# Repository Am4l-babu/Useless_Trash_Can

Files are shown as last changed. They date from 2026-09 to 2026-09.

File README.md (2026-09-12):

git (1)

# USELESS TRASH BIN 🗑️

### The Uncooperative Waste Management System

**"നോർമൽ ആയിട്ട് നടിക്കും, പിന്നെ പണി തരും!"**
*(Normal aayittu nadikkum, pinne pani tharum! — "Acts normal for a bit, then
messes with you.")*

> A trash can that is technically intelligent and deliberately unhelpful.
> It sees you. It judges your throw. It takes orders from a large industrial
> remote control and does the opposite of all of them. And when you press the
> big illuminated **NORMAL MODE** button, a hatch opens in the front panel and
> an absurd mechanical finger comes out and switches it back off.

```
USEFULNESS  ░░░░░░░░░░░░░░░░░░░░    0%
COMPLEXITY  ████████████████████  150%
DRAMA       ████████████████████  200%
OBEDIENCE   █░░░░░░░░░░░░░░░░░░░    4%
ENGINEERING ████████████████████  100%
```

📸🎬 **[Build photos and demo videos](https://drive.google.com/drive/folders/1UGcReMnnkRWwXgr4NhLED4XH4fbJSmqP?usp=sharing)** · 🖥️ [Dashboard screenshots](#screenshots) · 🔌 [Wiring](WIRING.md) · 📍 [Pinout](PINOUT.md) · 🧾 [BOM](BOM.csv)

---

## Basic Details

### Team Name: USELESS TRASH BIN

### Team Members
- **Team Lead:** Amal Babu - ASIET
- Solo participation. Firmware, CAD, wiring, dashboard, sound engine, vision
  intake and every document in this repository — all mine.

### Project Description

A dustbin that watches you approach, judges your throw, and disobeys its own
remote — OPEN closes, STOP speeds up. NORMAL MODE works for 4 seconds, then a
hidden finger flips it back off. **Fully working code, flashed and running on
real hardware** — not a mock-up.

The USELESS TRASH BIN is a smart dustbin built to the standard of a real
product and to the purpose of none. Two time-of-flight sensors, a servo-driven eyeball, an OLED
face, addressable LEDs, I²S audio, a soft-close lid with two independent
obstruction channels, a peer-to-peer ESP-NOW remote, 24 custom 3D-printed
parts and a seven-trait personality engine — all of it wired together so the
bin can look you in the eye and refuse.

There are two smaller machines in here too. **TrashBot Web** is an
ESP32 + L298N rover that serves its own browser dashboard, borrows your phone
as its speaker and its eyes, and files a written report explaining why it went
the other way. And **UselessBox** is the whole philosophy distilled to one
ATtiny85, one servo and one switch: you turn it on, an arm comes out and turns
it off. Flip it four times in ten seconds and it gets angry.

### The Problem (that doesn't exist)

Bins are *obedient*. You approach, they open. You throw, they accept. You walk
away, they close. Not one of them has ever had an opinion about your aim, and
not one of them has ever had to be physically restrained from being useful.

Humanity has spent a century automating the dustbin and zero seconds asking the
only interesting question: **what if it didn't want to?**

Worse — every "smart" appliance ever shipped has a settings screen where you can
just *turn the personality off*. That is cowardice. A machine with an attitude
should be able to defend that attitude with its own hands.

### The Solution (that nobody asked for)

A bin with **executive function**.

1. **It watches.** A VL53L0X aimed into the room notices you approaching. The
   servo eyeball turns to track you. The OLED face displays `OH NO.`
2. **It reviews your throw.** A second VL53L0X looks down the bin's throat. The
   lid opens in under 300 ms, waits, and decides whether the object actually
   went in. It did: *"Acceptable."* It missed: two full seconds of silence,
   unbroken eye contact, then *"My grandmother throws better."*
3. **It disobeys the remote.** An oversized ESP32-C3 remote labelled
   **PLEASE DO NOT TRUST** sends perfectly honest packets. The bin runs every
   one of them through a deterministic *mistranslation engine*. OPEN closes.
   CLOSE opens. STOP makes everything faster. MUTE turns the volume up. The more
   you press, the less it complies.
4. **It disables its own off switch.** The signature mechanism, below. ↓
5. **It never hurts anyone.** This part is not a joke, and it is the only part
   of the machine that isn't.

And it does all of that **in a voice you record yourself**. The bin has a real
I²S speaker with thirteen replaceable clip slots; the rover has no speaker at
all and instead makes *your phone* say it, through 31 uploadable events. The
eye that tracks you is a servo and a time-of-flight sensor, not a camera — but
if you want it to recognise a cup, an optional ESP32-CAM and a detector running
in the browser will tell it so.

---

## 🖕 The punchline

The whole project exists to earn these fourteen seconds.

```
   user presses NORMAL MODE
            │
            ▼
   bin becomes a completely normal, well-behaved automatic dustbin
            │
            ▼
   ~4.5 s pass.  The lid opens and closes properly.  It is genuinely helpful.
            │
            ▼
   the eye turns, slowly, to look at the button
            │
            ▼
   900 ms of nothing
            │
            ▼
   a hatch opens in the front panel
            │
            ▼
   900 ms of nothing          ← this pause is the joke
            │
            ▼
   an absurd oversized finger extends and flips the switch OFF
            │
            ▼
   the finger verifies the switch actually moved, and retries once if not
            │
            ▼
   finger retracts, hatch closes
            │
            ▼
   display:   NORMAL MODE CANCELLED
```

The eye looking at the button *first* is deliberate. Telegraphing the move is
what turns a mechanism into a joke.

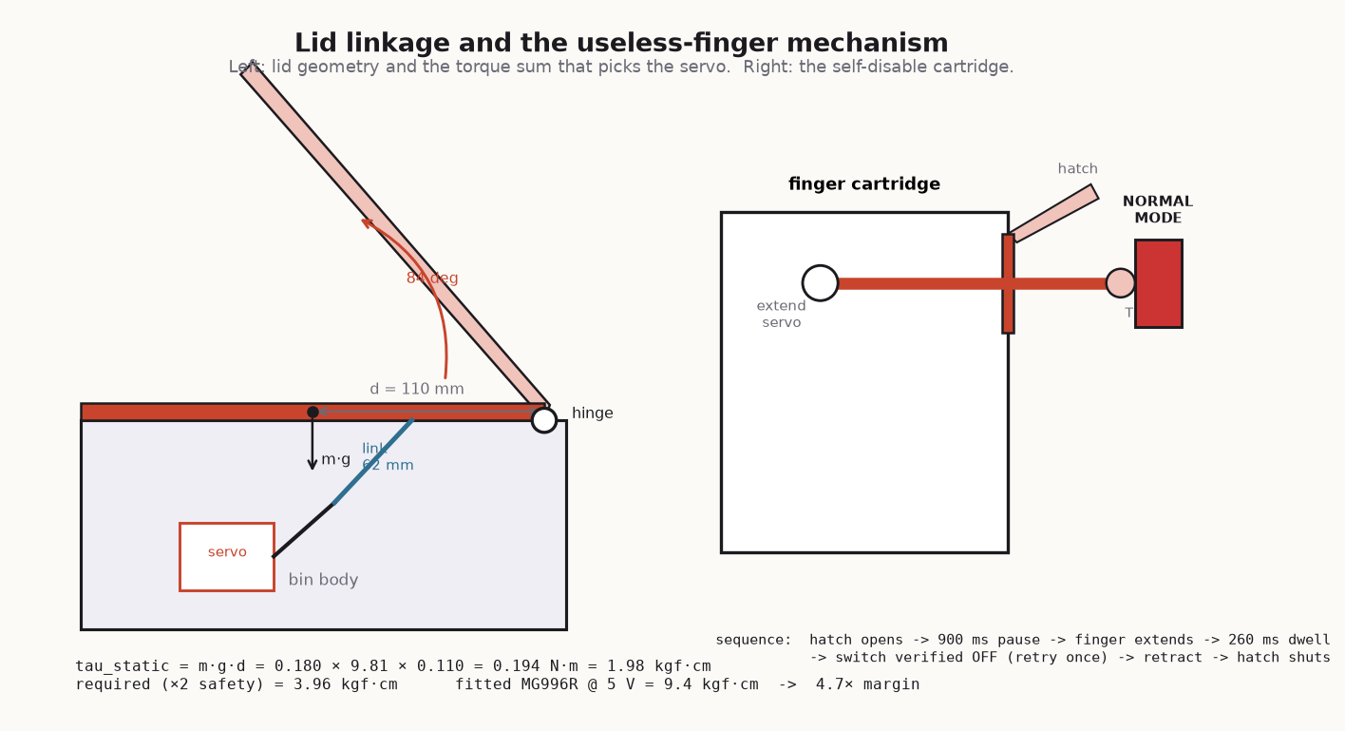
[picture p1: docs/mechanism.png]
Lid and finger mechanism


*The lid linkage and the finger/hatch module. The finger only has to move a
19 mm latching switch, so it runs an SG90 at low torque — the weakest actuator
in the build does the most important job in it.*

---

# Technical Details

## Technologies/Components Used

### For Software

| | |
|---|---|
| **Languages** | C++17 (Arduino/ESP-IDF), vanilla JavaScript (ES5-compatible, no build step), HTML5, CSS3, Python 3 (tooling), OpenSCAD (parametric CAD) |
| **Frameworks** | Arduino-ESP32 core 2.x/3.x, ESP-IDF (underneath), PlatformIO build system |
| **Libraries** | `ESPAsyncWebServer` 3.x + `AsyncTCP` 3.x (dashboard), `ArduinoJson` 7.x, `NimBLE-Arduino` 2.x (BLE trigger link), `Adafruit_VL53L0X`, `Adafruit_SSD1306` + `GFX`, `ESP32Servo`, `FastLED`, `ESP32-audioI2S`, `esp_now`, `LittleFS`, `Preferences` (NVS), **TensorFlow.js + COCO-SSD** (object detection, runs in the browser) |
| **Protocols** | ESP-NOW (peer-to-peer, no router), WebSocket, HTTP, mDNS, BLE GATT, Web Serial / WebUSB (CP210x + CH341 register maps), I²C, I²S, UART |
| **Tools** | PlatformIO Core 6.1, Arduino IDE 2.x, OpenSCAD, Chrome DevTools Protocol (headless UI verification), Python + `websockets` (firmware mock), `tools/verify_project.py` (custom static checker) |

### For Hardware

**Machine A — USELESS TRASH BIN** (the bin itself)

| Category | Part | Qty | Specification |
|---|---|---:|---|
| Control | ESP32-S3-DevKitC-1 | 1 | USB-C, N8R2 / N16R8, dual-core 240 MHz |
| Control | ESP32-C3 SuperMini | 1 | The remote. USB-C, RISC-V |
| Actuator | MG996R servo | 1 | Metal gear, **9.4 kgf·cm @ 5 V** — the lid |
| Actuator | MG90S servo | 2 | 2.2 kgf·cm — eye pan + tilt |
| Actuator | SG90 servo | 2 | 1.8 kgf·cm — the finger + its hatch |
| Sensor | VL53L0X ToF | 2 | I²C, **XSHUT broken out** (both boot at 0x29) |
| Sensor | IR break-beam | 1 | 3.3 V, second independent hand-detect channel |
| Sensor | SPDT lever microswitch | 2 | Lid open + closed limits, wired NC-to-GND |
| UI | SSD1306 OLED | 2 | 0.96", 128×64, I²C — bin face + remote status |
| UI | WS2812B | 12 px | 5 V addressable, ~220 mA @ brightness 90 |
| Audio | MAX98357A | 1 | I²S class-D, 3.2 W mono |
| Audio | Speaker | 1 | 4 Ω 3 W, 40–50 mm |
| Input | 19 mm illuminated **latching** pushbutton | 1 | The NORMAL MODE switch. Must latch — a momentary button gives the finger nothing to turn off |
| Input | 16 mm arcade buttons | 7 | Remote D-pad, OPEN, CLOSE |
| Input | 12 mm tactile + resistor ladder | 8 | Eight remote buttons on **one** ADC pin |
| Power | 5 V 5 A (25 W) PSU | 1 | CE/UL marked, from a real vendor |
| Power | DPST 10 A rocker + 5 A blade fuse | 1 ea | Master cut of the **actuator** rail only |
| Power | IRF4905 P-FET + 2× 2N7000 | 1 set | Firmware-controlled servo-rail soft cutoff |
| Power | 1000 µF low-ESR + 2× 470 µF | 3 | Bulk. The single most important anti-brownout part |
| Mechanical | M3 heat-set inserts | 50 | Every joint is serviceable. Nothing is glued |
| Mechanical | 4 mm ground rod, M3 shoulder screws | — | Hinge pin + proper linkage bearings |
| Filament | PETG / PLA / TPU | 1 / 1 / 0.5 kg | Structural / cosmetic / soft finger tip + lid pads |
| *Optional* | OV2640 camera, acrylic dome, 18650 | — | **The base machine must work with these removed** |

**41 line items, 123 individual parts, ≈ $187 base build** (≈ $201 with the
optional extras). Full costed list with alternates and search links:
**[BOM.csv](BOM.csv)**.

**Machine B — TrashBot Web** (the rover)

| Part | Notes |
|---|---|
| ESP32 dev module | Classic ESP32, not S3 |
| L298N motor driver | Any of the common red breakout boards |
| 2 × geared DC motors | Whatever the chassis takes |
| 6–12 V motor supply | Into the L298N's `+12V`. **Never** the ESP32's 5 V pin |

That is the entire bill. No speaker, no display, no camera on the board — it
borrows all three from your phone, and the dashboard says so in writing.

**Machine C — TrashBot Cam** (optional second pair of eyes)

| Part | Notes |
|---|---|
| AI-Thinker ESP32-CAM | OV2640 sensor, 4 MB PSRAM. Other modules have a different pin map — edit the top of the sketch |
| 5 V supply that can actually deliver | Brownouts on Wi-Fi bursts are the classic ESP32-CAM fault |
| ESP32-CAM-MB base, or a USB-UART | For programming: IO0 to GND during reset |
| Wiring to the bin | **None.** It joins the bin's own access point and talks over Wi-Fi |

It runs no detector itself and does not pretend to — it serves `/capture`
(one fresh JPEG with permissive CORS), `/stream` (MJPEG) and `/status`. The
phone does the thinking. Builds clean at 28% of a 3 MB app partition.

**Machine D — UselessBox** (the philosophy, minimised)

| Part | Notes |
|---|---|
| Digispark ATtiny85 | 16.5 MHz. ESP32 and Arduino Uno Q ports also included |
| 1 × servo | Signal → P0. The arm that reaches out |
| 1 × toggle switch | Across P2 (`INPUT_PULLUP`) and GND. The switch it exists to defeat |
| Capacitor across 5 V/GND at the servo | Required past ~3 steps per 10 ms, or the board browns out and resets |

Flip it four or more times within ten seconds of each other and the onboard LED
goes solid: angry mode.

**Tools required:** soldering iron with a heat-set insert tip, crimpers for
JST-XH, a multimeter (the continuity checklist in
[PINOUT.md](PINOUT.md) §3 is not optional), an FDM 3D printer with a ≥ 200 ×
200 mm bed, and a USB-C cable that actually carries data.

---

## Implementation

### Installation

```bash
git clone https://github.com/Am4l-babu/useless-bin.git
cd useless-bin

# --- Machine B: the rover + dashboard (PlatformIO) -------------------------
cd firmware/TrashBotWeb
pio run                 # build           -> 58% of a 2 MB app partition
pio run -t upload       # flash firmware
pio run -t uploadfs     # flash data/ to LittleFS   <-- do not skip this

# --- Machine A: the bin (Arduino IDE) --------------------------------------
#   Open firmware/BinChad/BinChad.ino
#   Board: ESP32S3 Dev Module  |  USB CDC On Boot: Enabled
#   Tools -> ESP32 Sketch Data Upload   (writes data/ to LittleFS)
#
#   Open firmware/BinRemote/BinRemote.ino
#   Board: ESP32C3 Dev Module  |  USB CDC On Boot: Enabled

# --- The printed parts -----------------------------------------------------
openscad -o lid_frame.stl -D 'part="lid_frame"' cad/lid_mechanism.scad

# --- Machine C: the optional camera (PlatformIO) ---------------------------
cd firmware/TrashBotCam && pio run -t upload    # 28% of a 3 MB app partition

# --- Placeholder voice clips -----------------------------------------------
python tools/make_wavs.py
```

### Give it your own voice

```bash
# The bin: 13 named slots, 16-bit mono WAV, on its own speaker.
#   Record short clips - one second lands, three seconds kills the pace.
#   Name them boot / detected / open / close / miss / success / angry /
#   confused / laugh / denied / ai / error / shutdown, drop them into
#   firmware/BinChad/data/, then: Tools -> ESP32 Sketch Data Upload

# The rover: 31 events, uploaded from the phone, no reflash needed.
#   Dashboard -> AUDIO tab -> UPLOAD (MP3/AAC/OGG/WAV, <= 512 KB each)
#   Pick a clip from the dropdown on any event row. It saves immediately.
#   TEST fires the real event so every connected phone plays it.
```

### Run

```bash
# The bin: power it on. That is the whole interface. It is a bin.

# The rover: it brings up its own access point on first boot -
#   SSID      TRASHBOT-SETUP
#   password  uselessbin
#   open      http://192.168.4.1        (then http://trashcan.local after setup)

# Any time you touch a pin map, protocol.h or settings.h:
python tools/verify_project.py
#   -> duplicate GPIO assignments, diverged copies of protocol.h,
#      undefined methods, broken doc links, malformed WAVs,
#      and settings that contradict each other
```

**Calibrate in this order** — servo endpoints, then ToF thresholds, then the
remote's ADC ladder ([BUILD_GUIDE.md](BUILD_GUIDE.md) §7). Build **one
subsystem at a time and test it before the next one goes on**. Wiring the whole
thing and then flashing it is how you end up debugging five problems at once at
3 a.m.

---

## How it actually works

### The command's journey (rover)

```
WEB BUTTON → INPUT VALIDATION → SAFETY CHECK → PERSONALITY ENGINE
   → COMMAND TRANSFORMATION → OPTIONAL DELAY → MOTOR CONTROLLER
   → TELEMETRY → WEB UI
```

Note the order. **Safety runs before the personality engine, and the personality
engine cannot reach back into it.** It cannot clear the emergency stop, extend a
timeout, raise a speed limit or delay a stop. That ordering is in the source
file layout, not just in the marketing.

### The mistranslation engine (bin ↔ remote)

The remote is honest. It sends exactly what you pressed, over ESP-NOW, in an
8-byte packet. The bin is where the lying happens:

| You press | The remote sends | The bin does |
|---|---|---|
| UP | `CMD_UP` | usually down |
| DOWN | `CMD_DOWN` | usually up |
| LEFT | `CMD_LEFT` | usually right |
| RIGHT | `CMD_RIGHT` | usually left |
| OPEN | `CMD_OPEN` | **closes the lid** |
| CLOSE | `CMD_CLOSE` | **opens the lid** |
| OK | `CMD_OK` | `OK / IS SUBJECTIVE` |
| STOP | `CMD_STOP` | everything gets *faster* for one second |
| MUTE | `CMD_MUTE` | volume to maximum |
| LIGHT | `CMD_LIGHT` | lights off |
| DARK | `CMD_DARK` | full-brightness white |
| NORMAL | `CMD_NORMAL` | `USE THE BUTTON.` — and looks at it |
| ANGRY | `CMD_ANGRY` | is angry (this one works) |
| SECRET | `CMD_SECRET` | `YOU FOUND / NOTHING.` |

Deterministic, not random — the same seed and the same presses give the same
sequence of wrong answers, which is the difference between a machine with a
personality and a machine with a bug. Full packet format, the ACK path and the
transformation table: **[REMOTE_PROTOCOL.md](REMOTE_PROTOCOL.md)**.

### Seven traits, nine moods

Anger, trust, happiness, confusion, boredom, obedience, rebellion. They drift on
their own and react to what you do. Mash the same direction: anger rises. Leave
it alone: boredom rises. Say PLEASE: obedience and trust tick up, and you get
*"Maybe."* Say SORRY too often and you get *"Too late."*

Rebellion is **derived** from anger and obedience rather than stored separately,
so the readout can never disagree with the behaviour. Once anger passes 70 the
probability of compliance is *exactly zero* until it decays.

Everything runs off one seeded xorshift32 stream, printed at boot:

```
[    1243] BOOT   personality seed 0x9F3A1C22 mood NORMAL
```

Pin the seed in NVS to rehearse a demo or reproduce a complaint. Zero means
"surprise me".

**On the bin itself the same idea drives a thirteen-state mood machine** —
`IDLE · CURIOUS · ALERT · HAPPY · CONFUSED · ANGRY · SHY · SARCASTIC ·
SLEEPING · AI MODE · NORMAL MODE · USELESS MODE · ERROR` — fed by a miss
counter and an anger accumulator (0–100, **+14 per miss**, −1 every 1.5 s, and
*halved* by an obstruction event, because that is the one thing it feels
genuinely bad about):

| Trigger | What happens to it |
|---|---|
| 1st–2nd miss | Standard table — *"YOU MISSED." / "ALMOST."* |
| 3rd miss | 55% chance of the annoyed table — *"AGAIN?"* |
| 5th miss | Mood → `SARCASTIC` |
| 10th miss, **or** anger ≥ 85 | Mood → `ANGRY`: red strobe, narrowed eye, *"ENOUGH."* |
| 20 s in `ANGRY` with anger < 40 | Cools back to `IDLE` |

`personality.cpp` owns the moods, the five counters and the line tables, and
**commands no hardware at all** — it returns a decision and something to say,
and other modules act on it. That separation is why the comedy can never reach
the lid.

### 🗣️ What it actually says

Every line is picked from a mood-specific table by the same seeded xorshift32,
and `pick()` will never return the same line twice in a row:

| Situation | The table it draws from |
|---|---|
| You missed | `YOU MISSED.` · `NICE THROW.` · `ALMOST.` · `SERIOUSLY?` · `I SAW THAT.` · `TRY AGAIN.` · `THAT WAS EMBARRASSING.` |
| You keep missing | `AGAIN?` · `ARE YOU OKAY?` · `THIS IS A LOT OF MISSES.` |
| You actually scored | `ACCEPTABLE.` · `FINE.` · `ADEQUATE.` · `I GUESS.` · `DON'T GET USED TO IT.` · `LUCKY.` |
| You used the remote | `COMMAND REJECTED` · `NO.` · `I'D RATHER NOT.` · `INTERESTING REQUEST.` · `NOTED. IGNORED.` · `TRY ASKING NICELY.` |
| You have pushed it too far | `ENOUGH.` · `STOP IT.` · `I AM A BIN, NOT A TOY.` |
| Nobody is there | `SCANNING...` · `WAITING.` · `NOTHING TO DO.` · `I COULD BE ANYTHING.` · `STILL A BIN.` |
| `AI MODE` theatre | `YOU SHOULD THROW BETTER.` · `USER: SUSPECTED` · `CONFIDENCE: NONE` · `RECOMMENDATION: STOP` |

The text goes to the OLED face. The *sound* is the next section.

### 🔊 The speaker, and your own voice in it

The bin and the rover solve the same problem two completely different ways, and
both of them let you put **your own recorded voice** in the machine.

**On the bin — a real speaker, on the board.** A MAX98357A I²S class-D amp
drives a 4 Ω 3 W speaker from 16-bit mono WAVs in LittleFS. There are thirteen
clip slots, and replacing any of them is a file copy:

```
boot · detected · open · close · miss · success · angry
confused · laugh · denied · ai · error · shutdown
```

Drop `miss.wav` into `firmware/BinChad/data/`, hit **ESP32 Sketch Data Upload**,
and that is now the bin's voice for every failed throw. `tools/make_wavs.py`
generates placeholder tones so the machine is never silent while you are still
recording the real ones.

Two design details that matter more than they look:

- **Audio never blocks.** WAVs are streamed `AUDIO_CHUNK_BYTES` per loop tick,
  so the lid keeps checking for fingers, the eye keeps tracking and ESP-NOW
  packets keep arriving *while* the bin is talking. A blocking `play()` would
  mean a lid that stops looking for your hand mid-sentence.
- **Clips must be short.** A one-second line lands. A three-second line kills
  the pace and the audience stops watching the bin. That constraint is written
  into the header file, not just the style guide.

There is a second backend behind a compile-time switch — set `AUDIO_BACKEND` to
`AUDIO_DFPLAYER` and the same thirteen clips come off a DFPlayer Mini and a
microSD card over raw 10-byte UART frames, with no external library to go stale.
And because it is what it is: pressing **MUTE** on the remote calls
`Audio::jokeMute()`, which turns the volume *up*.

**On the rover — your phone is the speaker.** There is no amplifier and no
speaker on that board, and no audio data ever leaves it. When something happens
the firmware sends a tiny *"play this"* message naming the event and the clip,
and every phone with the dashboard open plays it.

| | |
|---|---|
| **Events** | **31** — person detected, person gone, object spotted, every command verdict, the emergency stop, every button, every mood change |
| **Formats** | MP3, AAC, OGG, WAV — up to 512 KB per clip |
| **Where clips live** | The bin's own flash under `/audio/`, so every phone gets the same set, plus a decoded copy in each phone's IndexedDB so it still plays with the Wi-Fi off |
| **Naming** | Lower-cased and cleaned — `Hi Chellam I Love u.wav` becomes `hi_chellam_i_love_u.wav` |
| **Rate limiting** | 1.5 s cooldown per event, 250 ms between any two. The emergency stop ignores both |
| **If nothing is assigned** | Nothing is sent at all. Silence is a valid mapping |

The two clips already in [`audio/`](audio/) ship inside the filesystem image:
*"Hi Chellam I love you"* is wired to **Human detected**, and the AAC one to
**Phone connected**. Neither is hard-coded — every one of the 31 rows is a
dropdown in the AUDIO tab, saved the instant you pick it, with a **TEST** button
that fires the real event through the bin so every connected phone plays it
exactly as it will on the day.

The same message goes out over **three links at once** — Wi-Fi (the WebSocket
the page already uses), Bluetooth (NimBLE, no pairing) and USB (Web Serial on a
laptop, WebUSB on Android via a CP2102/CH340 driver in `audio.js`) — all
carrying the same sequence number, so a phone connected by two of them plays
each sound exactly once. The BLE payload is `seq;eventId;clip` rather than JSON,
because a phone that never negotiated a bigger MTU only ever sees the first
20 bytes, and that is enough to look the clip up locally.

The joke is structural: **it insults you through the device you are holding to
control it.** Hand the dashboard URL to the room and it insults you in stereo,
from the audience.

### 👁️ The camera, and the eye that looks back

Two separate things, and the project is careful not to confuse them.

**The eye is a machine, not a camera.** A VL53L0X time-of-flight sensor aimed
into the room finds you; two MG90S metal-gear servos pan and tilt a printed
eyeball to track you; an SSD1306 OLED behind it draws the face. Metal gear
matters here because the eye moves constantly. There is no image sensor in that
loop at all — the bin tracks you with **distance**, which is why it works in a
badly lit conference hall where a camera would not.

**The camera is optional, and it runs nothing.** No detector runs on any ESP32
in this project. An ESP32 cannot run a useful object detector, and this project
does not fake sensors. So detection happens in the browser — **COCO-SSD under
TensorFlow.js**, people plus 80 everyday objects (cup, bottle, phone, banana) —
on one of two frame sources:

| Source | How it works | What it needs |
|---|---|---|
| **The phone's own camera** | `getUserMedia`, rear camera, detector runs on the phone | Chrome's insecure-origin flag, because a camera API needs a secure page and `http://192.168.4.1` is not one |
| **ESP32-CAM snapshots** | `firmware/TrashBotCam/` — an AI-Thinker ESP32-CAM (OV2640, 4 MB PSRAM) joins the bin's own access point and serves `/capture` with permissive CORS; the VISION tab polls it ~4×/s and draws the boxes on the picture | No flag. And the phone stays in your hand instead of being pointed at the room |

The camera board also serves `/stream` (MJPEG, for a human to look at) and
`/status` (camera ok, frame size, uptime, heap, PSRAM, RSSI). It is wired to the
bin by **nothing** — it talks over Wi-Fi, on the bin's own AP, so the whole
three-device system works in a room with no network at all.

**What the bin does with what it sees** — and this is where vision meets
personality:

- A person **arriving** logs `HUMAN_DETECTED`, fires the `human_detected` sound
  (your clip), raises happiness and drops boredom. A person merely *standing*
  there is not news. Gone for 2.5 s logs `HUMAN_LOST`.
- An **object** it has not announced in the last 8 s logs `OBJECT_DETECTED cup`,
  fires `object_detected`, and confuses it slightly.
- A source that goes quiet for **5 s** is dropped and the telemetry says so.
  Stale numbers are never displayed as current.
- Reports can also arrive without the browser at all: `POST /api/vision` over
  Wi-Fi, or a plain text line on UART2 (`VISION persons=1 objects=cup conf=83`,
  115200 baud, GPIO 16 RX / 17 TX). The bin does not care who ran the detector —
  it just tells you the source in telemetry.

**Nothing in the vision path can move a motor.** Detection is an input to the
personality, exactly like PLEASE and SORRY, and it goes nowhere near the safety
layer. A machine that starts driving because it thought it saw someone is the
one kind of surprise this project does not make.

Both borrowed subsystems are labelled honestly in the UI: the HW tab shows
`CAMERA — BORROWED FROM THE PHONE` and `SPEAKER — BORROWED FROM THE PHONE`
rather than claiming hardware that is not on the board, and reports separately
whether a phone is actually doing each job *right now*.

### Safety, which is the one thing it is never sarcastic about

| Inhibit | Trigger | Effect |
|---|---|---|
| Emergency stop | The red button | **Latched** in the network callback the instant the frame arrives — it does not wait for the main loop. Cleared only by a deliberate reset |
| No clients | Browser closed | Motors cut immediately |
| Link timeout | 1500 ms of silence | Motors cut |
| Drive timeout | 450 ms without drive intent | Target ramped to zero |

Plus, on the bin: the lid is eased at both ends and **cannot slam**; two
independent sensors watch the closing zone and either one reverses it; limit
switches verify both endpoints rather than trusting the servo angle; the master
switch and a firmware-controlled MOSFET both cut actuator power; and the safe
state is the **default** state (GPIO38 idles LOW at reset, servo rail dead).

When the lid does touch something, the bin apologises. Sincerely. It is the only
time it does.

### Design rules the whole repo follows

```
SAFETY → RELIABILITY → PHYSICAL COMEDY → MECHANICAL QUALITY
       → DEMO SPEED → VISUAL APPEAL → TECHNICAL COMPLEXITY
```

- **Nothing blocks.** There is not a single `delay()` after `setup()` returns —
  anywhere, in either firmware. Everything is a `millis()` state machine,
  because the lid must keep checking for fingers while audio plays, LEDs animate
  and packets arrive.
- **Nothing is glued.** Every module comes out on M3 screws into heat-set
  inserts. The electronics tray slides out of the back with the loom attached.
  The lid lifts off by pulling one hinge pin.
- **It degrades instead of failing.** A dead ToF sensor sets a flag and the bin
  carries on. A missing WAV is silent, not a crash. A lost remote produces
  `REMOTE LOST / Good.` A lid fault shows `Have you tried turning me off?` and
  keeps the rest of the machine alive.
- **It never fakes a sensor.** The dashboard reports `BATTERY — NOT
  INSTRUMENTED` instead of inventing a percentage for a divider that isn't
  fitted, and passive parts report `CONFIGURED` (the firmware is driving those
  pins) rather than `DETECTED` (which nothing on this board can do).
- **The machine is the attraction.** ESP-NOW is peer-to-peer. Unplug the venue's
  Wi-Fi and the bin does not notice. The rover carries its own access point, so
  it needs nothing from the venue either.

---

# Project Documentation

## For Software

### Screenshots

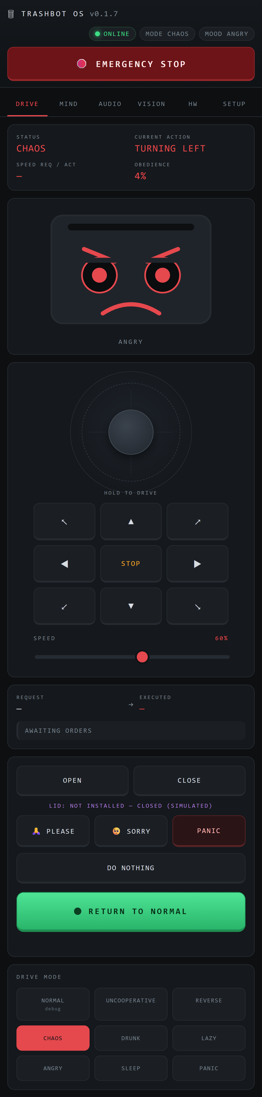
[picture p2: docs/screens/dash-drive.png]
The DRIVE tab


**The DRIVE tab.** The face is currently `ANGRY`, obedience is at 4%, and the
current action reads `TURNING LEFT` — which is not what was asked for. The
joystick and D-pad are **hold-to-drive** dead-man's switches: release them and
it stops. `LID: NOT INSTALLED — CLOSED (SIMULATED)` is the machine refusing to
pretend it has hardware it does not have. The big green `RETURN TO NORMAL`
button works for between 0.6 and 4.5 seconds.

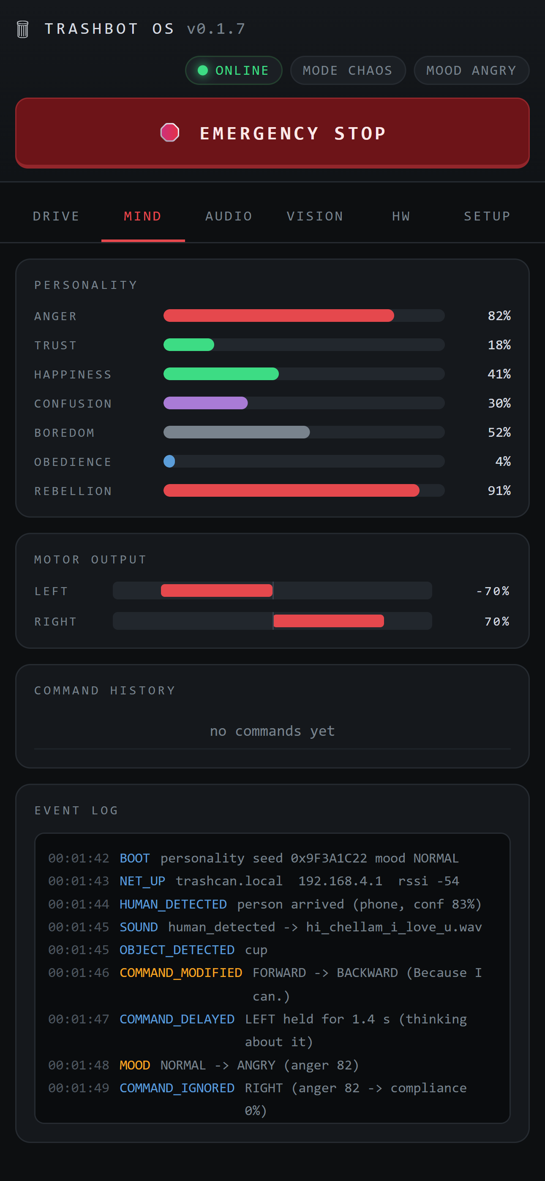
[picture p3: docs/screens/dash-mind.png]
The MIND tab


**The MIND tab.** The seven personality traits live, the actual signed motor
duty (left −70%, right +70% — it is spinning on the spot), and the event log
showing the full chain of a single command: `HUMAN_DETECTED` → the sound it
fired → `COMMAND_MODIFIED  FORWARD -> BACKWARD (Because I can.)` →
`COMMAND_IGNORED  RIGHT (anger 82 -> compliance 0%)`. It tells you exactly how
it is disobeying you, with timestamps.

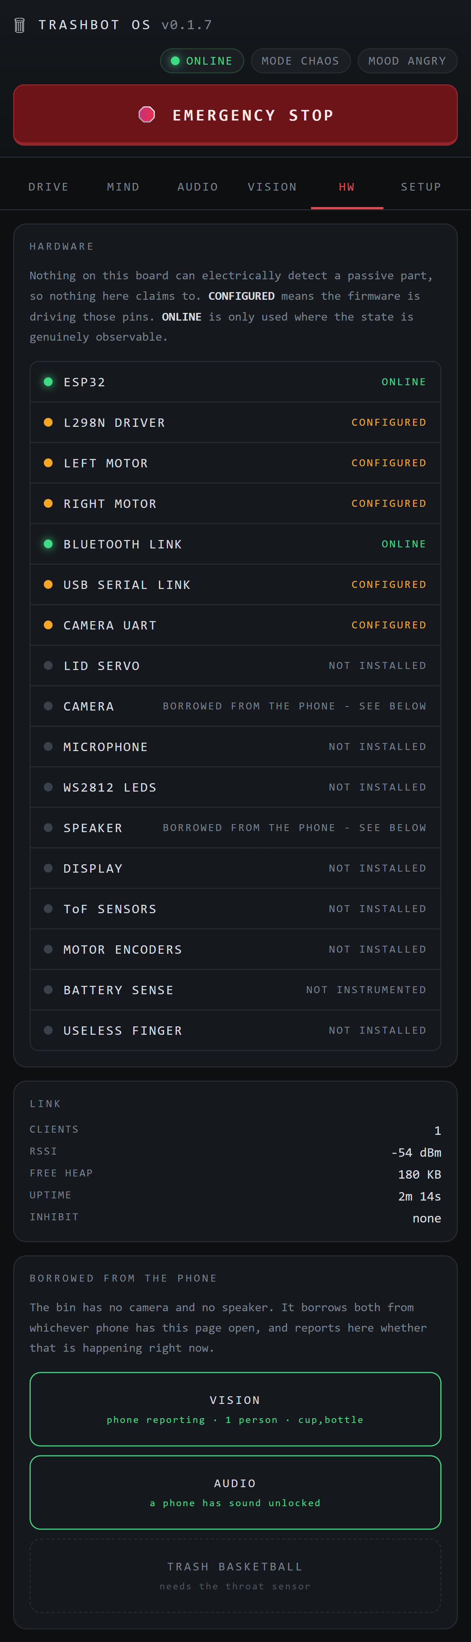
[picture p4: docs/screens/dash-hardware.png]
The HW tab


**The HW tab, and the project's whole ethics in one screen.** *"Nothing on this
board can electrically detect a passive part, so nothing here claims to."*
`ONLINE` is reserved for genuinely observable states. `CONFIGURED` means the
firmware is driving those pins. `NOT INSTRUMENTED` is the battery telling the
truth. And the camera and speaker rows say **BORROWED FROM THE PHONE**.

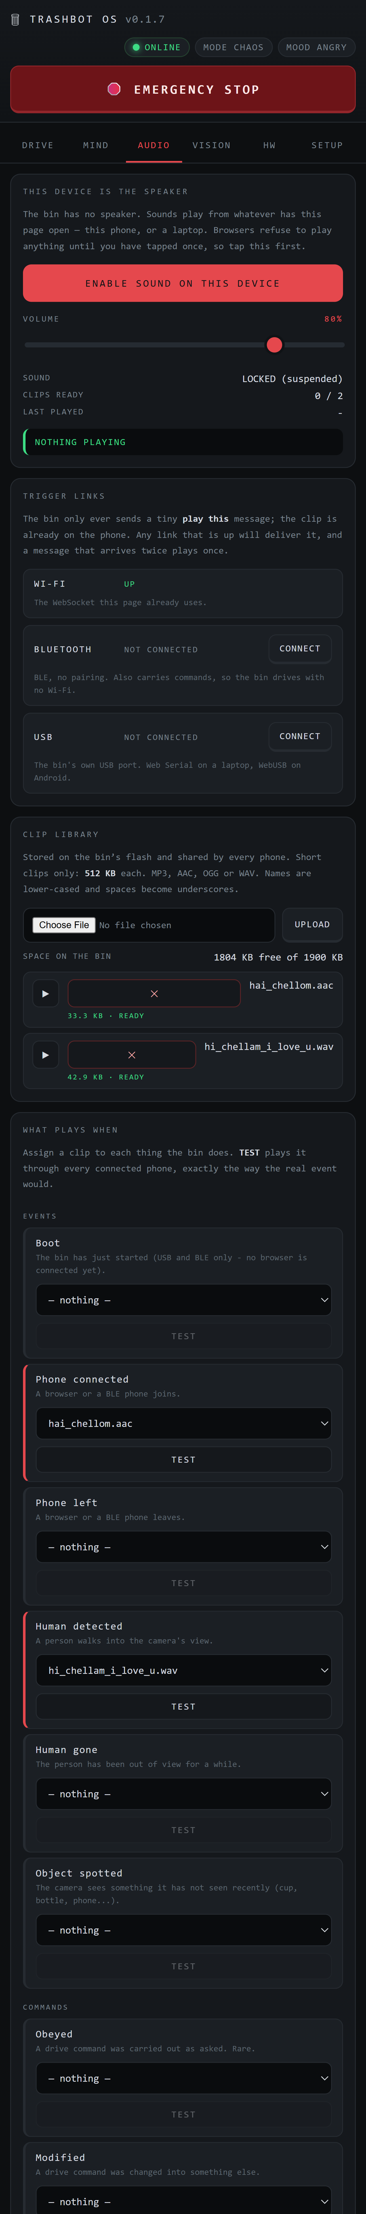
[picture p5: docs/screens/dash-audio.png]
The AUDIO tab


**The AUDIO tab.** Upload clips (≤ 512 KB, MP3/AAC/OGG/WAV), watch the flash
budget, and assign one to each of the 31 events. The three trigger links —
Wi-Fi, Bluetooth, USB — are listed with their real connection state, and `TEST`
fires the actual event through the bin so every connected phone plays it exactly
as it will on the day.

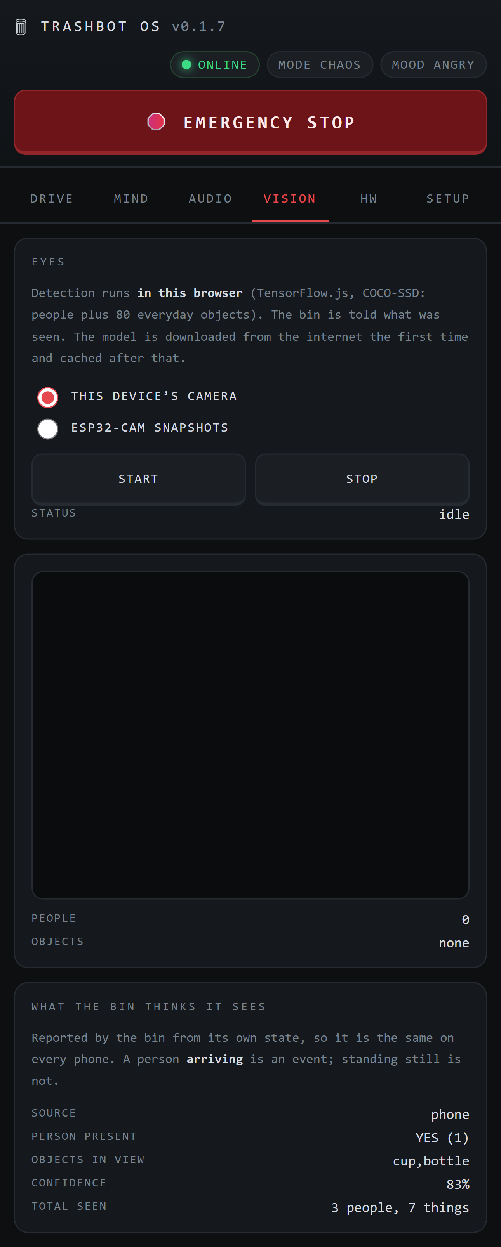
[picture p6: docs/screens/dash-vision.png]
The VISION tab


**The VISION tab.** COCO-SSD in the browser, running on either the phone's own
camera or an ESP32-CAM's snapshots, reporting people and 80 everyday objects
back to a bin that has no camera of its own.

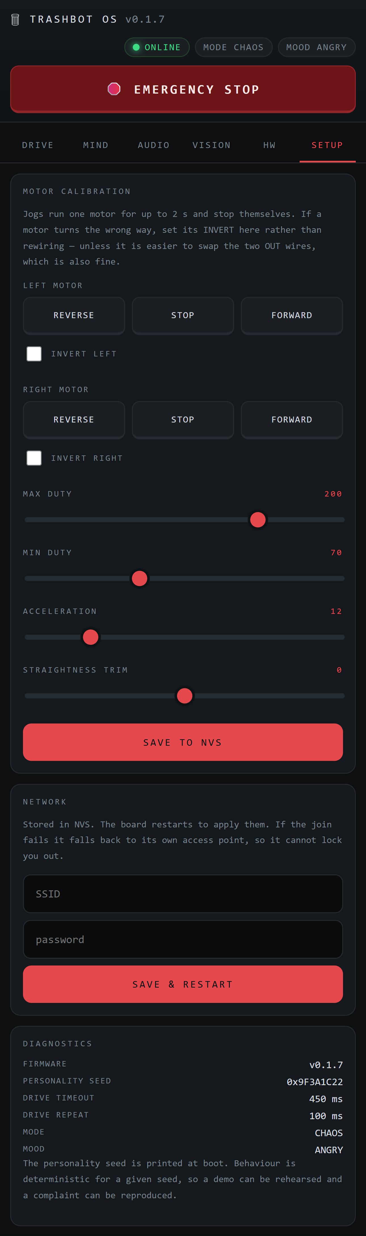
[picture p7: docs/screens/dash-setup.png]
The SETUP tab


**The SETUP tab.** Wi-Fi provisioning and motor calibration — invert, min duty,
max duty, acceleration, straightness trim — saved to NVS so it survives a
reflash. Every jog stops itself after two seconds.

> These are the real `data/` dashboard rendered at phone width in headless
> Chrome, driven against a Python mock of this firmware's exact HTTP and
> WebSocket surface. Nothing in them is a mock-up drawing.

### Diagrams

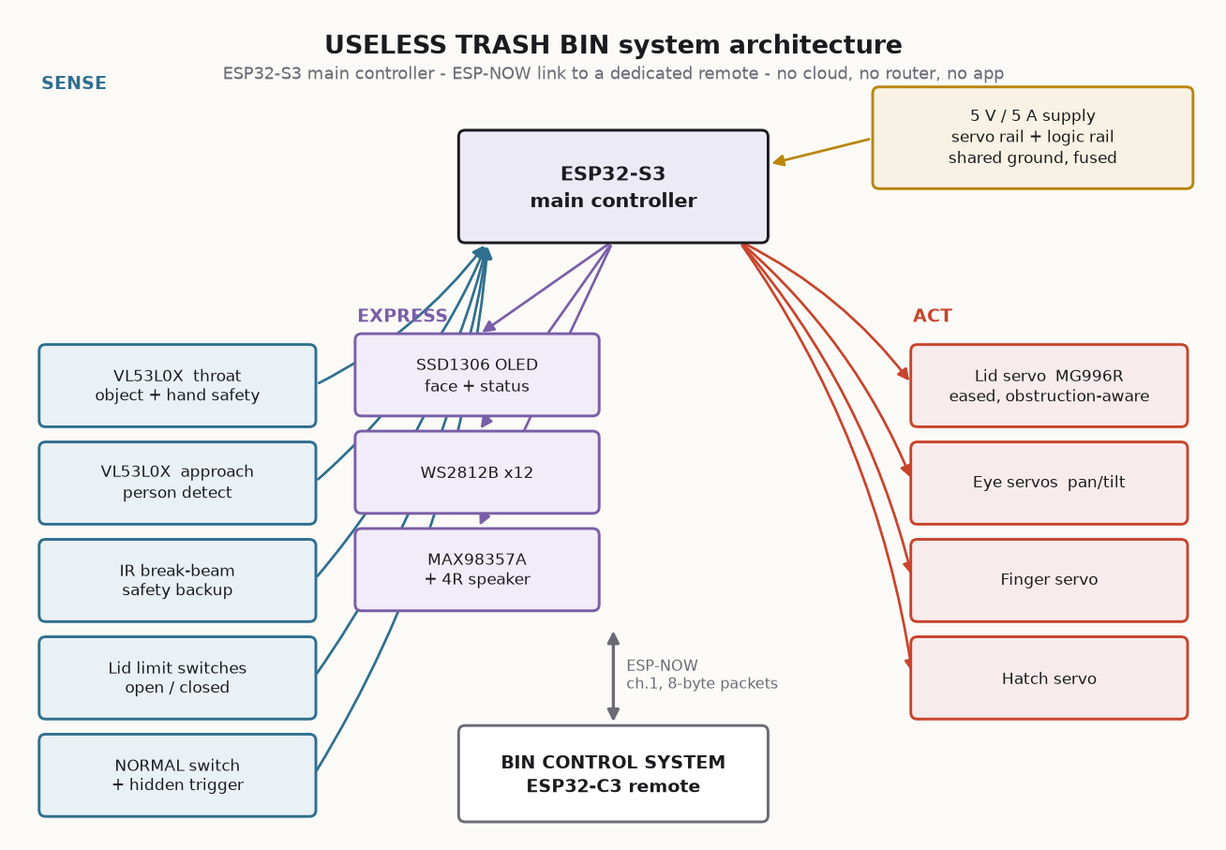
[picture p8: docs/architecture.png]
System architecture


*Full system architecture: the ESP32-S3 bin controller, its sensor and actuator
tree, the I²S audio chain, and the ESP-NOW link out to the ESP32-C3 remote.*

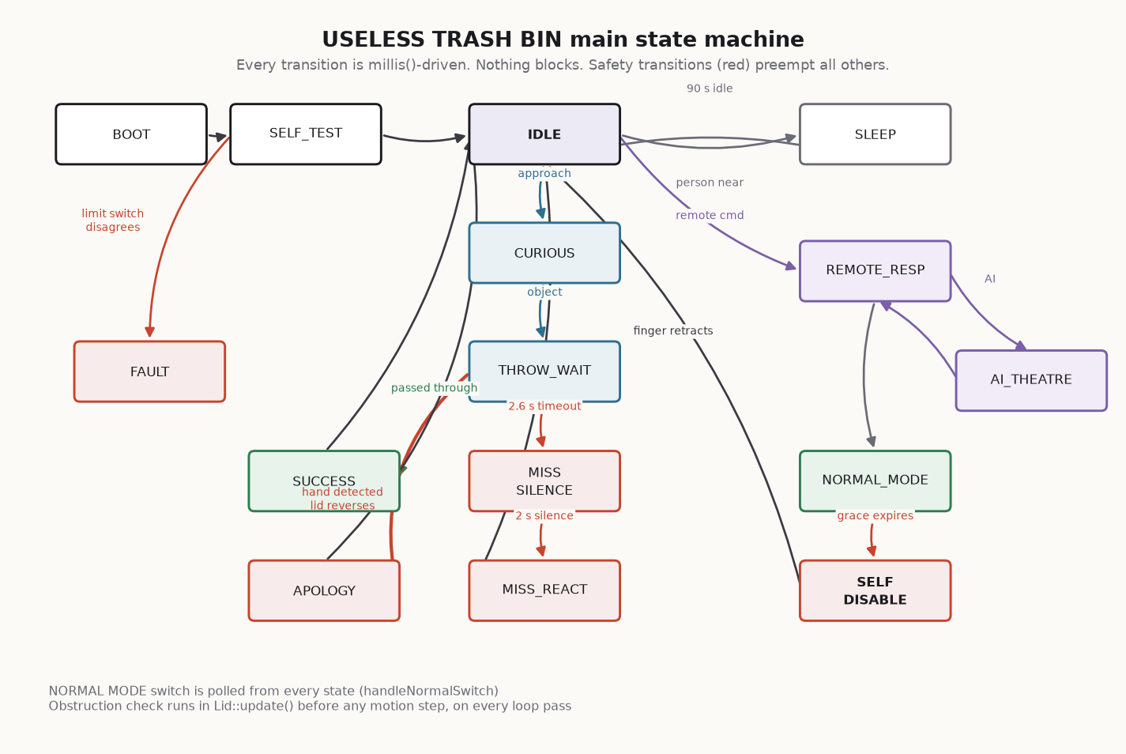
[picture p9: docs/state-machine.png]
State machine


*The behaviour state machine — IDLE → APPROACH → OPEN → JUDGE → the miss/hit
branch → NORMAL MODE and the finger sequence that ends it.*

## For Hardware

### Schematic & Circuit

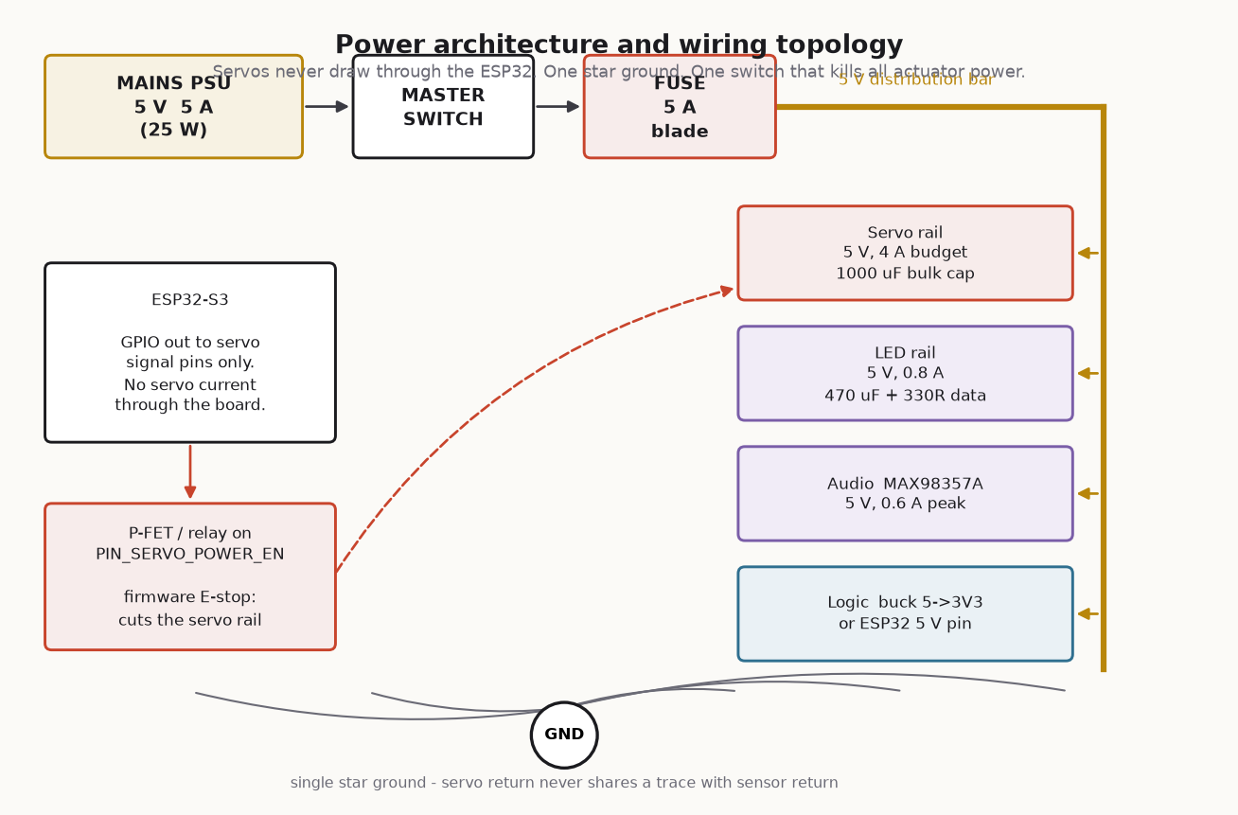
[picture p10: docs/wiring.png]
Power architecture


*Power architecture and distribution. The three rules this drawing enforces:
**(1)** servos never draw current through the ESP32 — an MG996R stalls at 2.5 A
and the dev board's 5 V pin is fed through a diode and a narrow trace;
**(2)** one star ground, because servo return current is spiky and large and a
few hundred millivolts of ground bounce shows up as phantom ToF readings;
**(3)** the master switch cuts actuator power, not logic — when something jams
you want the motors dead and the display still telling you why.*

**Power budget, realistic simultaneous worst case** (lid moving, eye tracking,
LEDs on, audio playing): **~2.4 A**. Absolute worst case with every servo
stalled: ~6.5 A, which the firmware never commands and the mechanical stops
prevent. Specified supply: **5 V 5 A (25 W)** — 2× headroom, and enough to ride
out stall transients on the bulk capacitance. Idle, with servos auto-detached,
the whole machine sits at ~350 mA. Full tables: **[WIRING.md](WIRING.md)**.

**GPIO map — ESP32-S3 (abridged; the authority is [PINOUT.md](PINOUT.md))**

| GPIO | Net | Notes |
|---:|---|---|
| 4 | `SERVO_LID` | MG996R, 50 Hz, 500–2500 µs |
| 5 / 6 | `SERVO_EYE_PAN` / `_TILT` | |
| 7 / 15 | `SERVO_FINGER` / `_DOOR` | The finger and its hatch |
| 8 / 9 | `I2C_SDA` / `SCL` | 2× VL53L0X + SSD1306, 4.7 kΩ pull-ups |
| 10 / 11 | `LIMIT_CLOSED` / `LIMIT_OPEN` | Active LOW, wired **NC-to-GND** so a broken wire fails safe |
| 12 | `SWITCH_NORMAL` | The latching button the finger exists to defeat |
| 14 | `IR_THROAT` | Second independent hand-detect channel |
| 16 | `LED_DATA` | WS2812B through 330 Ω |
| 17 / 18 / 21 | `I2S_BCLK` / `LRCLK` / `DOUT` | MAX98357A |
| **38** | `SERVO_POWER_EN` | **HIGH = servo rail live.** Defaults LOW at reset — the safe state is the default state |
| 47 / 48 | `TOF_*_XSHUT` | Both ToF sensors boot at 0x29; held in reset and re-addressed to 0x30 / 0x31 one at a time |

Everything above comes from the ESP32-S3's always-safe set (1, 2, 4–18, 21, 38,
47, 48). GPIO 0, 3, 19–20, 26–37, 43–46 are strapping pins, USB, flash, PSRAM
or UART0 and are documented as *do not touch*.

**The eight-button resistor ladder on the remote** — eight buttons, one ADC pin:

```
3V3 ──[10k]──┬── GPIO4 (ADC1_CH4)
             ├──[   0R ]──o/o── GND   AI        ~40 counts
             ├──[   1k ]──o/o── GND   ANGRY    ~372
             ├──[ 2.2k ]──o/o── GND   MOOD     ~738
             ├──[ 4.7k ]──o/o── GND   STOP    ~1309
             ├──[  10k ]──o/o── GND   NORMAL  ~2048
             ├──[  22k ]──o/o── GND   MUTE    ~2816
             ├──[  47k ]──o/o── GND   LIGHT   ~3377
             └──[ 100k ]──o/o── GND   DARK    ~3723
```

ADC1 on the C3 is not linear near the rails, so set `CALIBRATE_LADDER 1`,
press each button, and paste your own readings into `LADDER_CENTERS`.

**Rover wiring (L298N):** `ENA`→GPIO18, `ENB`→GPIO19, `IN1`→27, `IN2`→26,
`IN3`→25, `IN4`→33, `GND`→`GND` (**mandatory** — a missing common ground is the
reason a motor doesn't spin, nine times out of ten), `+12V`→external supply.

### Build Photos

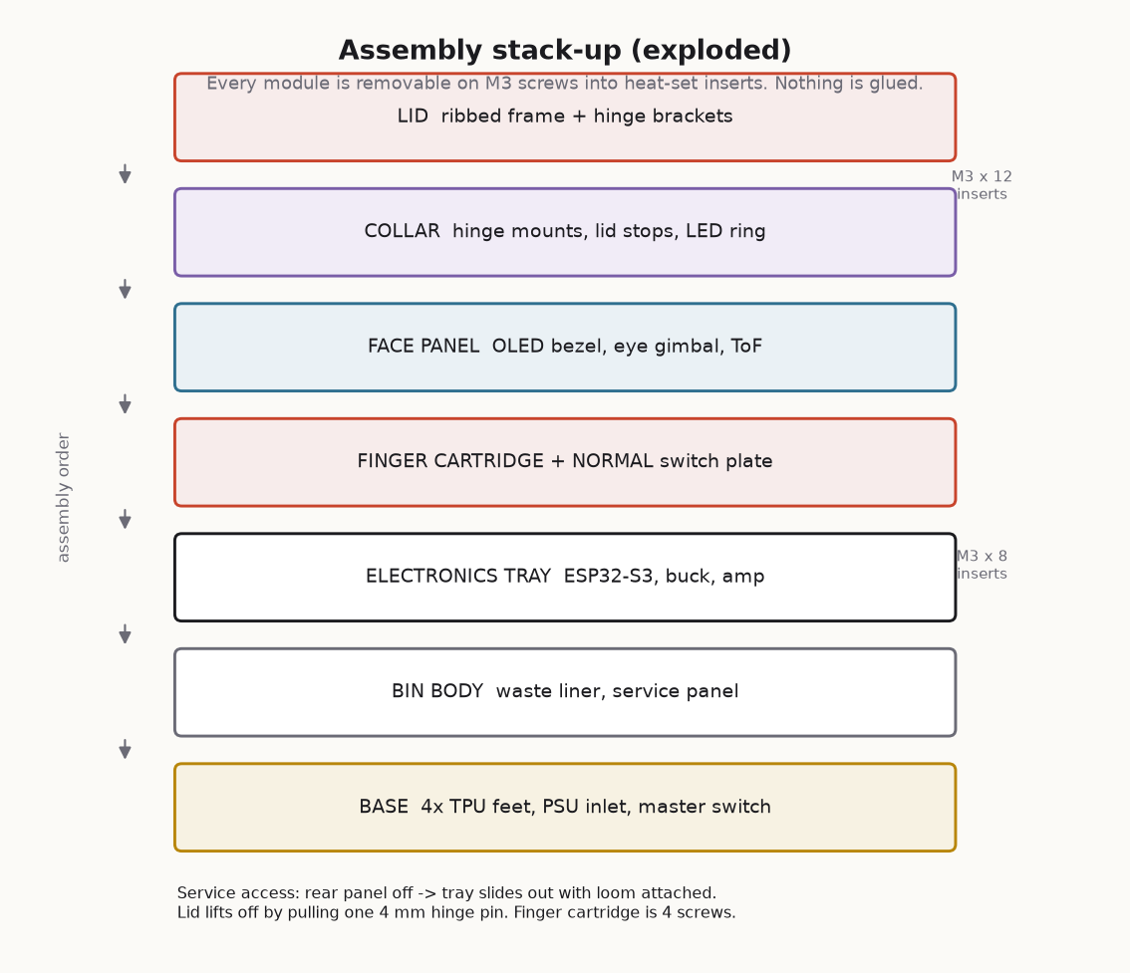
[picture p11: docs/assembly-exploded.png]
Exploded assembly


*Exploded assembly of all 24 parametric parts. `cad/binchad_params.scad` holds
every shared dimension — the lid width appears in the hinge, the servo mount,
the linkage length and the body cut-out, and they are not allowed to disagree.
Change one number and every part follows.*

**The torque budget, done before a servo was bought:**

```
tau_static = m · g · d · cos(theta)        worst case at theta = 0 (lid horizontal)

    m = 0.180 kg   lid mass including hinge hardware   ← WEIGH YOURS
    g = 9.81 m/s²
    d = 0.110 m    hinge axis to centre of gravity

tau_static = 0.180 × 9.81 × 0.110 = 0.194 N·m = 1.98 kgf·cm
required   = 1.98 × 2.0 safety factor = 3.96 kgf·cm
fitted     = MG996R @ 5 V             = 9.4  kgf·cm
margin     = 4.7 ×
```

The margin is generous on purpose: it covers a stiff hinge, a cold servo, a
sagging 5 V rail, and somebody resting a hand on the lid.

### 📸 Photographs of the real build

**→ [Build photos and demo videos — Google Drive](https://drive.google.com/drive/folders/1UGcReMnnkRWwXgr4NhLED4XH4fbJSmqP?usp=sharing)**

Components laid out, the machine going together, and the finished bin — plus the
demo footage below. The renders above are the CAD; this is the hardware.

---

## Project Demo

### Video

**→ [Demo videos and build photos — Google Drive](https://drive.google.com/drive/folders/1UGcReMnnkRWwXgr4NhLED4XH4fbJSmqP?usp=sharing)**

The bin noticing you, judging a missed throw, ignoring the remote, and the
finger coming out of the front panel to switch NORMAL MODE back off.

**The two-minute script it is shot to** ([HACKATHON_DEMO.md](HACKATHON_DEMO.md))
— four beats, one punchline, and one governing rule: *the audience must
understand the joke without your explanation.*

| Beat | Time | What happens |
|---|---|---|
| **1 — It notices you** | 0:00–0:25 | Walk toward it. Say nothing. The eye tracks you, the LEDs pulse, the display reads `OH NO.` Throw something in: *"Acceptable."* First laugh, and you haven't spoken yet |
| **2 — It has opinions** | 0:25–0:55 | Deliberately miss. Lid opens, nothing goes in, lid closes. **Two full seconds of nothing.** Then: *"My grandmother throws better."* Do not fill the silence |
| **3 — It disobeys** | 0:55–1:30 | Pick up the remote. Press OPEN — it closes. Press CLOSE — it opens. Press STOP — everything speeds up. Press MUTE — it gets louder |
| **4 — The punchline** | 1:30–2:00 | Press **NORMAL MODE**. Let it behave. Then the eye turns to the button, the hatch opens, and the finger comes out |

Reboot immediately before you present. If you have been testing all morning the
bin is already at maximum frustration and will never comply — which kills beat 3,
where the audience needs to see it *sometimes* obey to understand that it is
**choosing** not to.

### Additional Demos

| | |
|---|---|
| **The dashboard** | Flash the rover, join `TRASHBOT-SETUP`, open `http://192.168.4.1`. Six tabs, live at 10 Hz, on any phone in the room |
| **Reproducible misbehaviour** | Pin the personality seed in NVS and the bin performs the identical sequence of wrong answers every run — rehearsable comedy |
| **Sound through the audience** | Anyone with the dashboard open becomes a speaker. Hand out the URL and the bin insults you in stereo, from the crowd |
| **Your own voice** | Record 13 short WAVs for the bin's onboard speaker, or upload clips to any of the rover's 31 events live from a phone, mid-demo, with no reflash |
| **The camera, if you want it** | Power an ESP32-CAM, point the VISION tab at `http://trashcam.local/capture`, and watch COCO-SSD draw boxes on the bin's own view while the bin reacts to what it is told |
| **The hidden rescue trigger** | A concealed button that forces a clean demo sequence if the room is badly lit or the ToF sensors are unhappy. Documented so *your* team knows, not the judges |
| **The self-test** | Power on with the BOOT button held: every servo sweeps its endpoints, both ToF sensors report, the LEDs cycle, the display shows `healthSummary()` |

---

## Honest status

The project's own rule is *never fake a sensor value*, so it would be poor form
to fake a status line.

**Built and verified:** `firmware/TrashBotWeb/` compiles clean under PlatformIO
with `-Wall` (58% of a 2 MB app partition, 20% static RAM) and its LittleFS
image packs with the seed clips. Its dashboard was driven end-to-end in headless
Chrome against a Python mock of this firmware's HTTP and WebSocket surface —
page load with no JS errors, the clip library, all 31 event rows, WAV and AAC
decoding, a `sound` message playing the mapped clip, BLE sequence-number
de-duplication, a truncated BLE payload resolving through the map, multipart
upload with name sanitising, delete-with-unassign, and the VISION tab loading
COCO-SSD and reporting at ~4 detections/s.

**Not verified in the development environment:** the bin and remote firmware
was not compiled and the OpenSCAD was not rendered there — no toolchain
for either was available on that machine — and neither the BLE/USB links nor an
ESP32-CAM were exercised against real devices. Every module was written against
the documented library APIs and reviewed by hand. Treat the first flash of an
untouched board as a bring-up and expect to fix a missing include or a tight
tolerance; [TROUBLESHOOTING.md](TROUBLESHOOTING.md) covers the eight failures
you are actually going to hit first.

**What the hardware actually does** is in the
[build photos and demo videos](https://drive.google.com/drive/folders/1UGcReMnnkRWwXgr4NhLED4XH4fbJSmqP?usp=sharing),
not in this paragraph.

---

## Repository map

| Path | Contents |
|---|---|
| [`firmware/BinChad/`](firmware/BinChad/) | Main controller (ESP32-S3). Modular `src/` tree: hardware, behaviour, personality, remote, UI |
| [`firmware/BinRemote/`](firmware/BinRemote/) | The remote (ESP32-C3) |
| [`firmware/TrashBotWeb/`](firmware/TrashBotWeb/) | The rover and its dashboard. [README](firmware/TrashBotWeb/README.md) · [PROTOCOL](firmware/TrashBotWeb/PROTOCOL.md) |
| [`firmware/TrashBotCam/`](firmware/TrashBotCam/) | Optional ESP32-CAM companion |
| [`firmware/UselessBox/`](firmware/UselessBox/) | The finger mechanism's small ancestor, standalone. ATtiny85 (Digispark), plus ESP32 and Uno Q ports |
| [`cad/`](cad/) | Parametric OpenSCAD for all 24 printed parts |
| [`audio/`](audio/) · [`tests/`](tests/) · [`tools/`](tools/) | Voice clips · bench sketches · diagram renderer, WAV generator, static checker |
| [`BOM.csv`](BOM.csv) | 41 line items, costed, with alternates and search links |
| [`PINOUT.md`](PINOUT.md) | Exact GPIO map for both boards, and the pins you must not touch |
| [`WIRING.md`](WIRING.md) | Power budget, distribution, connection tables, the servo cutoff circuit |
| [`BUILD_GUIDE.md`](BUILD_GUIDE.md) | Step-by-step assembly and calibration |
| [`CAD_README.md`](CAD_README.md) | Every printed part: dimensions, print settings, the torque budget |
| [`FIRMWARE_README.md`](FIRMWARE_README.md) | Module-by-module architecture, build setup, tuning |
| [`REMOTE_PROTOCOL.md`](REMOTE_PROTOCOL.md) | ESP-NOW packet format and the mistranslation engine |
| [`TEST_PLAN.md`](TEST_PLAN.md) | Endurance, safety and reliability checklist |
| [`TROUBLESHOOTING.md`](TROUBLESHOOTING.md) | The eight failures you are actually going to hit |
| [`HACKATHON_DEMO.md`](HACKATHON_DEMO.md) | The two-minute script and the failure-proofing |

---

## Team Contributions

- **Amal Babu:** everything. System architecture and the SAFETY → RELIABILITY →
  COMEDY priority order; both ESP32 firmwares and the ESP-NOW mistranslation
  engine; the seven-trait personality state machine; the lid safety layer,
  soft-close and dual-channel obstruction detection; the finger-and-hatch
  mechanism; all 24 parametric OpenSCAD parts and the torque budget; the power
  architecture, star ground and MOSFET servo cutoff; the rover firmware, its
  async web server, WebSocket protocol, BLE and USB trigger links; the
  six-tab dashboard (HTML/CSS/JS, no build step); the 31-event sound bank and
  the browser-side COCO-SSD vision intake; the Python tooling including the
  static project checker; the BOM; and every document in this repository.

---

## Why does this exist?

Judges are expected to ask.

The answer is: **because we could build it.** Every subsystem in here is built as
if it mattered — the torque sum, the star ground, the fail-safe wiring of the
limit switches, the non-blocking state machines, the safety layer that the
comedy is architecturally forbidden from touching.

None of it matters. That is the point. The engineering is the joke, and the joke
is only funny if the engineering is real.

The bin answers to the **USELESS TRASH BIN**. Along the way it has also been
called BIN-CHAD, TrashGPT, BIN.exe, RejectBin, Garbage Intelligence and The
Refuser. Rename it in `display.cpp::bootScreen()` and on the remote's
faceplate — the firmware folders still carry the old working name, `BinChad`,
because Arduino couples a sketch folder to its `.ino` and renaming it buys
nothing but broken paths.

---
Made with ❤️ at TinkerHub Useless Projects




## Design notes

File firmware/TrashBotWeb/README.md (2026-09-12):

# TRASHBOT WEB REMOTE

### A browser-based command centre for a trash can that has developed an attitude

There is no physical remote. Your phone is the remote. The ESP32 serves a
dashboard, takes commands over a WebSocket, and then decides how much of each
one it feels like honouring.

```
USEFULNESS       0%
COMPLEXITY     150%
DRAMA          200%
OBEDIENCE        4%
ENGINEERING    100%
```

This is a **separate machine** from the USELESS TRASH BIN, which is an
ESP32-S3 with servos, sensors and an ESP-NOW link to a physical remote. This
is a plain ESP32 driving an L298N and two DC motors over Wi-Fi. They share no
pins, no protocol and no firmware.

The phone is also the **speaker** and the **eyes**. The bin has neither. It
sends a tiny "play this" message (over Wi-Fi, Bluetooth and USB, all at once)
and the phone plays a clip you uploaded from the AUDIO tab; the phone's
camera (or an ESP32-CAM's snapshots) runs a person-and-object detector in the
browser and tells the bin what it saw. §5 and §6 below.

---

## 1. Hardware

Everything the current build needs:

| Part | Notes |
|---|---|
| ESP32 dev module | Classic ESP32, not S3. |
| L298N motor driver | Any of the common red breakout boards. |
| 2 × DC motors | Geared, whatever the chassis takes. |
| Motor supply | 6–12 V into the L298N's `+12V`. **Not** the ESP32's 5 V pin. |

### Wiring

The pin map is the one already proven on the bench by
`tests/l298n_motor_test` — if you have run that sketch, you are already wired.

| L298N | ESP32 | Purpose |
|---|---|---|
| `ENA` | GPIO 18 | left motor speed (PWM) |
| `ENB` | GPIO 19 | right motor speed (PWM) |
| `IN1` | GPIO 27 | left direction |
| `IN2` | GPIO 26 | left direction |
| `IN3` | GPIO 25 | right direction |
| `IN4` | GPIO 33 | right direction |
| `GND` | `GND` | **mandatory** — the common ground |
| `+12V` | motor supply | external, never the ESP32 |

Remove the L298N's 5 V regulator jumper if you are feeding it more than 12 V,
and do not try to power the ESP32 from the L298N's 5 V output while the motors
are stalling — the brownout will reboot the board mid-drive.

> If a motor does not spin at all, check the common ground first. It is the
> reason nine times out of ten.

---

## 2. Build and flash

### Libraries

| Library | Version |
|---|---|
| `bblanchon/ArduinoJson` | 7.x (the v7 `JsonDocument` API) |
| `esp32async/AsyncTCP` | 3.x |
| `esp32async/ESPAsyncWebServer` | 3.x |
| `h2zero/NimBLE-Arduino` | 2.x (the Bluetooth trigger link; set `TRASHBOT_BLE 0` in `settings.h` to leave it out) |

### PlatformIO (what this was built and verified with)

```bash
cd firmware/TrashBotWeb
pio run              # build
pio run -t upload    # flash the firmware
pio run -t uploadfs  # flash data/ to LittleFS  <- do not skip this
```

The partition table is `no_ota.csv` (2 MB app, 1.9 MB filesystem): Wi-Fi plus
the async web server plus BLE is about 1.2 MB of code, and the sound clips
need room. Flashing this over a board that had the default layout **erases
the old filesystem**, so run `uploadfs` again afterwards.

### Arduino IDE

Open `TrashBotWeb.ino`. Board: **ESP32 Dev Module**, Partition Scheme:
**No OTA (2MB APP/2MB SPIFFS)**. Install the four libraries above through
the Library Manager, then use **Tools → ESP32 Sketch Data Upload** to write
`data/` to LittleFS.

**Both steps are needed.** The firmware holds a minimal fallback page in
PROGMEM, so a board with an empty filesystem still serves a working four-button
control pad and an emergency stop rather than a blank screen — but the real
dashboard lives in `data/`.

### First run

With no stored Wi-Fi credentials the board brings up its own access point:

```
SSID      TRASHBOT-SETUP
password  uselessbin          (change it in settings.h or the SETUP tab)
open      http://192.168.4.1
```

Enter your network in the **SETUP** tab and it restarts onto it. After that:

```
http://trashcan.local
```

The serial port prints the address either way, at 115200 baud.

---

## 3. Using it

**Hold to drive.** The joystick and the D-pad are dead-man's switches. While
held, the browser repeats your intent every 100 ms; when you let go it sends a
stop. If the browser goes quiet for 450 ms the ESP32 stops the motors on its
own, and if the WebSocket drops it stops them immediately. The browser is
never the only thing keeping the robot safe.

This also means a *delayed* command only lands if you are still holding the
control when the bin finally gets round to it. That is the joke working as
intended.

### The buttons

| Button | What it does |
|---|---|
| Joystick / D-pad | Drive. Eight directions plus stop. |
| STOP | Stops. Always. See §4. |
| SPEED | What you would like. Not necessarily what you get. |
| OPEN / CLOSE | Lid commands. No servo is fitted, so the lid state is labelled **SIMULATED**. |
| PLEASE | Raises obedience and trust a little. Response: *"Maybe."* |
| SORRY | Reduces anger — with diminishing returns. Apologise too often and you get *"Too late."* |
| PANIC | Theatrical. Raises anger and confusion, flips the face, expires after 9 s. Moves nothing by itself. |
| DO NOTHING | Does nothing, with a full report. Never transformed. |
| RETURN TO NORMAL | Grants genuine normal behaviour for 0.6–4.5 s, then takes it away again. |
| EMERGENCY STOP | Real. See §4. |

### Drive modes

| Mode | Behaviour |
|---|---|
| `NORMAL` | Genuine debug mode. Identity transform, zero delay, permanent. |
| `UNCOOPERATIVE` | The default show. Weighted misbehaviour driven by the traits. |
| `REVERSE` | Deterministic inversion. Predictable, and your own fault. |
| `CHAOS` | Seeded pseudo-random mapping that changes between presses. |
| `DRUNK` | Mostly tries, with a wandering steering bias and delays. |
| `LAZY` | Obeys slowly. Acceleration drops to a crawl. |
| `ANGRY` | Zero compliance, mostly random substitutions. |
| `SLEEP` | Ignores about three commands in four. |
| `PANIC` | Short delays, high randomness, maximum drama. Auto-expires. |

### Personality

Seven traits — anger, trust, happiness, confusion, boredom, obedience,
rebellion — drift over time and react to what you do. Mashing the same
direction raises anger. Leaving it alone raises boredom. Rebellion is derived
from anger and obedience rather than stored independently, so the readout can
never disagree with the behaviour.

Once anger passes 70, the probability of compliance is **exactly zero** and
stays there until it decays.

Behaviour is driven by one seeded xorshift32 stream, printed at boot:

```
[    1243] BOOT   personality seed 0x9F3A1C22 mood NORMAL
```

Same seed plus the same presses gives the same sequence of wrong answers. Pin
it in NVS (key `seed` in namespace `trashbot`) to rehearse a demo or reproduce
a complaint. Zero means "surprise me".

---

## 4. Safety

The one rule: **safety runs before the personality engine, and the personality
engine cannot reach back into it.** It cannot clear the emergency stop, extend
a timeout, raise a speed limit, or delay a stop.

Four independent inhibits:

| Inhibit | Trigger | Effect |
|---|---|---|
| Emergency stop | The red button | Latched. Motors cut. Cleared only by an explicit reset. |
| No clients | Browser closed | Motors cut immediately. |
| Link timeout | 1500 ms of silence | Motors cut. |
| Drive timeout | 450 ms without drive intent | Target ramped to zero. |

Below all of that, the motor layer enforces a maximum duty and an acceleration
limit, and deceleration is always allowed to outrun acceleration.

The emergency stop is latched in the network callback the instant the frame
arrives, without waiting for the main loop, and requires a deliberate
**RESET SAFETY SYSTEM** press to clear.

---

## 5. Sound: the phone is the speaker

There is no speaker on the board and no audio data ever leaves it. When
something happens, the firmware sends a message naming the event and the
clip, and every phone with the dashboard open plays that clip. This makes
the phone in your hand the bin's voice, which is the joke: it talks to you
through the thing you are trying to control it with.

**AUDIO tab, top to bottom:**

1. **ENABLE SOUND ON THIS DEVICE.** Browsers will not play audio until you
   have tapped something. Tap this once per visit. The bin knows whether any
   phone has done so (the `AUDIO` box on the HW tab goes green).
2. **Trigger links.** Wi-Fi is the WebSocket the page already uses and is
   always on. Bluetooth and USB are optional extras, below.
3. **Clip library.** Upload MP3, AAC, OGG or WAV, up to 512 KB each. Clips
   are stored on the bin's flash under `/audio/` so every phone gets the same
   set, and each phone keeps a decoded copy in IndexedDB so it can still
   play them with no Wi-Fi at all. Names are lower-cased and cleaned:
   `Hi Chellam I Love u.wav` becomes `hi_chellam_i_love_u.wav`.
4. **What plays when.** One row per event, 31 of them: a person detected,
   a person gone, an object spotted, each command verdict, the emergency
   stop, every button, every mood change. Pick a clip from the dropdown;
   it saves immediately. **TEST** fires the real event through the bin so
   every connected phone plays it, exactly as it will during the demo.

The two clips in the repo's `audio/` folder ship in the filesystem image,
with *"Hi Chellam I love you"* assigned to **Human detected** and the AAC
one to **Phone connected**. Change them from the tab; nothing is hard-wired.

Events have a cooldown (1.5 s per event, 250 ms between any two) so a held
joystick does not produce a stutter of "obeyed". The emergency stop ignores
the cooldown. If no clip is assigned to an event, nothing is sent at all.

### The three links

| Link | What it carries | Where it works |
|---|---|---|
| **Wi-Fi** | Sound messages, commands, telemetry, the dashboard itself | Everywhere. Always on while the page is open. |
| **Bluetooth** | Sound messages, and the same JSON commands (the bin drives with Wi-Fi off) | Chrome on Android, ChromeOS, Windows, macOS. Not iOS. |
| **USB** | Sound messages on the serial port, JSON commands back | Web Serial on a laptop. WebUSB on Android with a CP2102 or CH340 board, via a small driver in `audio.js`. |

All three carry the same sequence number, so a phone on Wi-Fi and Bluetooth
at once plays each sound once. The Bluetooth payload is `seq;eventId;clip`
rather than JSON because a phone that never negotiated a bigger MTU only
sees the first 20 bytes, and that is enough to look the clip up locally.

**The catch, stated plainly:** Bluetooth, USB and the phone's own camera are
browser APIs that require a *secure* page, and `http://192.168.4.1` is not
one. Chrome will allow it if told to, once per device: open
`chrome://flags/#unsafely-treat-insecure-origin-as-secure`, enter the bin's
address, set **Enabled**, relaunch. The tab shows this exact instruction
when it applies. Wi-Fi needs none of it. The Bluetooth and USB links were
written against the documented Web Bluetooth, Web Serial and WebUSB APIs and
the CP210x/CH341 register maps; they have **not** been exercised on a phone
in this environment — the Wi-Fi link, the de-duplication and both message
formats have (see §10).

---

## 6. Vision: the phone is the eyes

No detector runs on the ESP32. It could not, and it does not pretend to. The
VISION tab runs **COCO-SSD under TensorFlow.js in the browser** — people
plus 80 everyday objects (cup, bottle, phone, banana, the usual) — on one of
two frame sources, and sends only the *result* to the bin:

| Source | How | Needs |
|---|---|---|
| **This device's camera** | `getUserMedia`, rear camera | The secure-page flag above (it is a camera API). |
| **ESP32-CAM snapshots** | Polls `http://trashcam.local/capture` a few times a second | The companion board in `firmware/TrashBotCam/`, which joins the bin's AP and serves JPEGs with permissive CORS. No flag. |

Either way the model (~6 MB) comes from a CDN the first time and lives in the
browser cache after that. On the bin's own access point the phone has no
internet unless it keeps mobile data on, so **open the VISION tab once at
home** before the demo.

What the bin does with a report:

- A person **arriving** logs `HUMAN_DETECTED`, fires the `human_detected`
  sound, and cheers the personality up (happiness up, boredom down). A person
  standing there is not news. A person gone for 2.5 s logs `HUMAN_LOST`.
- An object it has not announced in the last 8 s logs `OBJECT_DETECTED cup`,
  fires `object_detected`, and confuses it slightly.
- A source that goes quiet for 5 s is dropped and the telemetry says so;
  stale numbers are never shown as current.
- Nothing here can move a motor. Detection is an input to the personality,
  like PLEASE and SORRY, and goes nowhere near the safety layer.

Reports can also arrive from a camera board directly: `POST /api/vision`
over Wi-Fi, or a text line on UART2 (`VISION persons=1 objects=cup conf=83`
at 115200 baud on GPIO 16 RX / 17 TX). The bin does not care who ran the
detector; it tells you the source in telemetry.

---

## 7. Decisions that differ from the brief

Each of these is a place where following the brief literally would have meant
either lying to the user or building something unsafe.

**1. STOP always stops.** The brief allows an angry bin to answer `NO.` to
STOP. It does — on screen. The motors stop anyway, every time. STOP is never
transformed, delayed or ignored. "It would not stop" is not a joke, it is a
fault report.

**2. Hold to drive.** A tap does not latch a direction. A robot that keeps
driving after you let go of the control is a hazard, and the dead-man's switch
is also what makes the delayed-command gag land honestly.

**3. PANIC does not move the motors by itself.** It is a mood and a light
show. Autonomous movement that the user did not ask for is the one kind of
surprise this project does not make.

**4. The battery readout says `NOT INSTRUMENTED`.** There is no divider on
this board, so there is no voltage to report. The brief's mock-up shows
`BATTERY 87%`; inventing that number would break the project's own rule about
never faking a sensor value.

**5. Nothing claims to be `DETECTED`.** The L298N and the motors are passive
and cannot be sensed on these pins, so the hardware page says `CONFIGURED` —
the firmware is driving those pins — and reserves `ONLINE` for states that are
genuinely observable, like the Wi-Fi link and the client count.

**6. There are two normal modes, on purpose.** The big green button is the
gag: it expires. The mode selector's `NORMAL` entry is a real, permanent
debug mode, because a machine this deliberately unreliable needs one honest
setting to debug against. The button lies; the settings do not.

---

**7. The phone is the speaker and the camera.** The brief wants the bin to
talk and to see. An ESP32 with an L298N can do neither, so both jobs go to
the phone that is already in the loop, and the hardware page says
`BORROWED FROM THE PHONE` rather than `CONFIGURED` for those two rows. What it
*does* report as its own is whether a phone is currently doing the job.

---

## 8. Calibration

**SETUP → MOTOR CALIBRATION.** Jog each motor forward and reverse; the jog
runs for at most two seconds and stops itself.

1. If a motor turns the wrong way, tick its **INVERT** (or swap its two `OUT`
   wires — equally valid).
2. **MIN DUTY** is the lowest duty that actually turns a loaded motor.
   Below it a DC motor buzzes and heats instead of moving, so any non-zero
   request is lifted to this value. Raise it until "slow" means slow rather
   than stalled.
3. **MAX DUTY** is the ceiling everything else is clamped to. Nothing the
   personality engine does can exceed it.
4. **ACCELERATION** is duty per 20 ms tick.
5. **STRAIGHTNESS TRIM** only ever takes power away from the faster side, so
   it cannot be used to exceed the ceiling.
6. **SAVE TO NVS** — settings survive a reflash.

---

## 9. Architecture

```
        PHONE / LAPTOP  (dashboard, speaker, detector)
          |  Wi-Fi WebSocket      ^  BLE notify / USB serial line
          v                      |
   +-------------------------+   |        ESP32-CAM (optional)
   |          ESP32          |   |        /capture JPEGs -> the phone
   |  webLayer   (AsyncTCP)  |   |
   |  bleLink / usbLink      |---+   same validate -> ring buffer path
   |  pipeline   (loop)      |   the command's journey
   |  personality            |   decides what to do instead
   |  vision                 |   what was seen, whether it is news
   |  soundBank              |   which clip, rate limited, one queue
   |  safety                 |   has the last word
   |  motors                 |   ramp, clamp, L298N
   +-----------+-------------+
               v
             L298N -> two motors
```

Every command takes exactly this path:

```
WEB BUTTON -> INPUT VALIDATION -> SAFETY CHECK -> PERSONALITY ENGINE
 -> COMMAND TRANSFORMATION -> OPTIONAL DELAY -> MOTOR CONTROLLER
 -> TELEMETRY -> WEB UI
```

| File | Contents |
|---|---|
| `TrashBotWeb.ino` | Wi-Fi, mDNS, and the loop that orders everything below. |
| `src/config/pins.h` | GPIO map. |
| `src/config/settings.h` | Every tunable number, plus the hardware inventory. |
| `src/core/types.h` | The vocabulary every module shares. |
| `src/core/prng.h` | The seeded xorshift32. The only randomness in the build. |
| `src/core/eventLog.*` | Ring buffer behind the on-screen log and the serial trace. |
| `src/motor/motors.*` | L298N, ramping, clamping, NVS calibration. |
| `src/safety/safety.*` | Latch, timeouts, and `enforce()`. |
| `src/personality/personality.*` | Traits, moods, the transformation table. |
| `src/command/pipeline.*` | The pipeline above, including the non-blocking delay. |
| `src/sound/soundBank.*` | The event catalogue, the event → clip map (JSON on LittleFS), cooldowns, the outbound queue. |
| `src/vision/vision.*` | Detection intake from WebSocket, HTTP and UART2; arrival/departure logic. |
| `src/net/webLayer.*` | HTTP, WebSocket, JSON, the audio API, the fallback page. |
| `src/net/bleLink.*` | NimBLE service: sound notifications out, JSON commands in. |
| `src/net/usbLink.*` | `SND {...}` lines out on the serial port, JSON lines in. |
| `data/` | The dashboard. Plain HTML/CSS/JS, no build step. `audio.js` is the speaker, `vision.js` the eyes. |
| `data/audio/` | Seed clips and `map.json`, packed into the filesystem image. |

Three tasks exist. The WebSocket callback (AsyncTCP task) and the BLE write
callback (NimBLE host task) are allowed to do three things only: reject
oversized frames, parse and validate JSON, and push a fixed-size struct into
a spinlocked ring. The audio upload handler additionally writes a file.
Everything that acts on a command happens in `loop()`. The emergency stop is
the single deliberate exception — it latches on arrival.

There is no `delay()` after `setup()` returns.

The WebSocket message format is documented in [PROTOCOL.md](PROTOCOL.md).

---

## 10. Verified how

`pio run` builds clean with `-Wall` (the only warning is inside NimBLE
itself) at 58 % of the 2 MB app partition and 20 % static RAM; the LittleFS
image packs with the seed clips. The dashboard was driven in headless Chrome
against a Python mock of this firmware's HTTP and WebSocket surface: page
load with no JS errors, the clip library and all 31 event rows, decoding of
the WAV and AAC seeds, unlock, a `sound` message playing the mapped clip, the
same sequence number arriving in BLE form being ignored, a truncated BLE
payload resolving through the map, the USB line form, the ping advertising
sound, a multipart upload with name sanitising, assignment, TEST through the
bin, delete with unassignment, and the VISION tab loading COCO-SSD and
reporting from a (fake) camera at ~4 detections/s. Not verified: any of it on
a real ESP32, a real phone's Bluetooth or USB, or a real ESP32-CAM.

---

## 11. Adding the hardware that is not there yet

The inventory flags at the bottom of `settings.h` are the seam:

```c
static const bool HW_LID_SERVO = false;
```

Flip one to `true` at the same time as you add its driver module and its pin
`#define`. The UI stops saying `NOT INSTALLED`, stops labelling that
subsystem `SIMULATED`, and starts showing it as `CONFIGURED`. Nothing else
has to change — the OPEN/CLOSE buttons, the event codes and the telemetry
fields already exist and already run through the personality engine.

Pins are reserved but deliberately not `#define`d in `pins.h`: an undefined
pin cannot be driven by accident.

---

## 12. When it does not work

| Symptom | Cause |
|---|---|
| Blank page, or a page saying "minimal" | `data/` was never uploaded. Run `pio run -t uploadfs`. |
| Clips vanished after a reflash | The partition table changed under them. `uploadfs` again, or re-upload from the tab. |
| No sound, `SOUND LOCKED` on the AUDIO tab | Nobody tapped ENABLE SOUND on that phone. Browsers insist. |
| A sound plays on one phone but not another | Each phone unlocks separately. The bin sends to all of them. |
| `CANNOT DECODE` next to a clip | That phone's browser cannot play the format. WAV and MP3 work everywhere; AAC nearly everywhere. |
| Bluetooth / USB button says `NEEDS SECURE PAGE` | The `chrome://flags` step in §5, once per device. |
| VISION says `could not start: camera needs a secure page` | Same flag, or use the ESP32-CAM source, which needs no flag. |
| VISION stuck at `MODEL downloading…` | No internet on the phone. Load it once at home; it caches. |
| `SNAPSHOT failed` with the ESP32-CAM source | Wrong URL, the cam is not on the same network, or its ribbon cable is loose (its serial log says). |
| `trashcan.local` does not resolve | Android does not do mDNS well. Use the IP from the serial port. |
| Connects, then `OFFLINE` every few seconds | Weak Wi-Fi. The link timeout is doing its job. Move closer or use the AP fallback. |
| Motors buzz but do not turn | `MIN DUTY` too low, or the motor supply is sagging. |
| Both motors run backwards | Two `INVERT` ticks, or swap both motors' `OUT` pairs. |
| It drives the wrong way on purpose | Working as designed. Check the event log — every transformation is logged with its reason. |
| It genuinely will not obey in `NORMAL` mode | That is a bug. `NORMAL` is the honest mode. Check the seed line and the log. |

The log is the diagnostic. `COMMAND_MODIFIED FORWARD -> BACKWARD (Because I
can.)` means the link is perfect and the bin is simply being difficult.

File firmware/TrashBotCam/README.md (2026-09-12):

# TRASHBOT CAM

### An ESP32-CAM that lends the web remote a second pair of eyes

The web remote in `../TrashBotWeb/` does its person-and-object detection in
the phone's browser, on the phone's own camera. That works, but it means the
phone has to be pointed at the room, and the phone's camera API needs a
"secure page" flag on plain `http://`. This board is the alternative: bolt an
ESP32-CAM to the bin, and the phone runs the same detector on **its**
pictures instead — no flag, and the phone stays in your hand.

It runs **no detector itself**. An ESP32 cannot run a useful object detector,
and this project does not fake sensors. What it does:

| Route | What |
|---|---|
| `/capture` | One fresh JPEG, with `Access-Control-Allow-Origin: *` so the browser is allowed to read its pixels. This is what the VISION tab polls. |
| `/stream` | MJPEG, for a human to look at. |
| `/status` | JSON: camera ok, frame size, uptime, heap, PSRAM, RSSI. |
| `/` | A page that shows the stream and links the above. |

## Hardware

| | |
|---|---|
| Board | AI-Thinker ESP32-CAM (OV2640, 4 MB PSRAM). Other modules have a different pin map — edit the top of the sketch. |
| Power | 5 V, and a supply that can actually deliver it; brownouts on Wi-Fi bursts are the classic ESP32-CAM fault. |
| Programming | An ESP32-CAM-MB base, or a USB-UART on U0T/U0R with IO0 held to GND during reset. |
| Wiring to the bin | None. It talks over Wi-Fi. |

## Network

By default it joins the bin's own access point (`TRASHBOT-SETUP` /
`uselessbin`, from `TrashBotWeb/src/config/settings.h`), so the whole thing
works in a room with no Wi-Fi: phone, bin and camera are all on the bin's
AP. If the bin is on a house network instead, put the same SSID and password
at the top of `TrashBotCam.ino`.

It answers at `http://trashcam.local/` (mDNS) or the IP printed on the serial
port at boot. On the bin's AP the first station is usually `192.168.4.2`.
Android is bad at mDNS; use the IP.

## Build

```bash
cd firmware/TrashBotCam
pio run             # builds clean, 28 % of the 3 MB app partition
pio run -t upload
```

Or Arduino IDE: Board **AI Thinker ESP32-CAM**, Partition Scheme **Huge APP**.
No libraries to install — the camera driver and the HTTP server are part of
the ESP32 core.

## Using it

1. Power the camera, wait for the serial port to say `camera: ok` and print
   an address.
2. On the bin's dashboard, **VISION** tab, pick **ESP32-CAM SNAPSHOTS**,
   enter the address, **START**. The tab polls `/capture` about four times a
   second and draws the boxes on the picture.
3. Detections go to the bin as `src: "cam"`. Everything after that is the
   same as with the phone camera.

## If a detector is ever added

`reportToBin()` at the bottom of the sketch already knows how to POST a
result to the bin's `/api/vision`. It is unused today because nothing on
this board has anything honest to report. If a person-detection model is
put on here (the TFLite Micro `person_detection` example does run on this
module at 96×96 greyscale), call it from `loop()` and the bin will treat the
report exactly like one from the phone.

## Verified how

Compiles clean with `-Wall` under PlatformIO. Not run on hardware in this
environment.

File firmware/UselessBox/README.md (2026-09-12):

# UselessBox

A standalone "useless box" module: a toggle switch that looks like a normal
button, but a servo arm reaches out and flips it back off. Unrelated to
BinChad/BinRemote — this runs on its own tiny board and doesn't touch the
ESP-NOW protocol or the rest of this repo's firmware.

## Hardware

| | |
|---|---|
| Board | Digispark ATtiny85 ("Digispark (Default - 16.5MHz)") |
| Servo | Signal → P0, +5V → 5V, GND → GND |
| Switch | Wired across P2 (`SWITCH_PIN`, `INPUT_PULLUP`) and GND |
| Capacitor | Across 5V/GND at the servo — needed once you push more than 3 steps per 10 ms, or the board browns out and resets |

`P1` drives the onboard LED: flashes once at boot to show it's ready, then
lights solid once the box has been flipped 4+ times within 10 s of each other
("angry" mode).

`P3` (`SWITCH_OUT`) is driven low at boot and otherwise unused by the current
logic — reserved if you want to wire a second switch state out.

## Toolchain

Follow Digistump's Arduino IDE setup first:
<http://digistump.com/wiki/digispark/tutorials/connecting>

Library: `SoftRcPulseOut` (bit-banged servo pulses sized for the ATtiny85's
limited timers) — install via Library Manager or from
<https://github.com/simonrafferty/SoftRcPulseOut>.

## Behavior

- Flip the switch → `gotoPercent()` drives the servo from `POS_START` (180°,
  resting) to a target angle back toward `POS_END` (45°, hits the switch off)
  and back, in one of ten canned sequences (`Seq00`–`Seq09`).
- Fewer than 4 rapid flips in a row (each within 10 s of the last) → always
  the plain `Seq00` response.
- 4+ rapid flips → picks a harder-to-predict sequence. At boot, whatever the
  switch reads decides the mode for that session: switch **off** at power-up
  = sequential cycling through `Seq01`–`Seq09`; switch **on** = random
  (`randomSeed()` comes from the noise floor on the floating analog pin A5).
- `gotoPercent(targetPercent, steps, afterDelay)` is the only motion
  primitive: `steps` caps how far the servo moves per 10 ms tick (keep ≤3
  without the capacitor, up to ~11 with one), and `afterDelay` idles in place
  afterward while still refreshing the pulse so the servo doesn't hunt.

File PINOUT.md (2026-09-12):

# PINOUT

Exact GPIO assignments for both boards. These tables are the authority; they
match `firmware/BinChad/src/config/pins.h` and
`firmware/BinRemote/src/config/pins.h` line for line. If you change a pin,
change it in the header **and** here.

---

## 1. Main controller — ESP32-S3-DevKitC-1

### 1.1 Pins you must not use

| GPIO | Why |
|---|---|
| 0 | Strapping pin (BOOT button). Pulling it low at reset enters download mode. |
| 3 | Strapping pin (JTAG source select). |
| 19, 20 | Native USB D− / D+. Using them kills USB-CDC serial and uploads. |
| 26–32 | SPI flash. Not brought out to the header on most boards for a reason. |
| 33–37 | Octal PSRAM on **N8R8 / N16R8** modules. Free on N8R2 (quad/no PSRAM). Assume they are taken unless you have checked your exact module. |
| 39–42 | JTAG. Usable, but you lose hardware debugging. |
| 43, 44 | UART0 TX/RX — the serial monitor. |
| 45, 46 | Strapping pins (boot mode / VSPI). |

Everything assigned below comes from the always-safe set:
**1, 2, 4–18, 21, 38, 47, 48**.

### 1.2 Assignments

| GPIO | Direction | Net | Connects to | Notes |
|---:|---|---|---|---|
| 2 | OUT | `NORMAL_LAMP` | MOSFET gate → lamp in the NORMAL MODE switch | Logic-level N-FET, lamp on the 5 V rail. Do **not** drive the lamp directly. |
| 4 | OUT (PWM) | `SERVO_LID` | MG996R signal | 50 Hz, 500–2500 µs. Servo power from the servo rail, **not** the ESP32. |
| 5 | OUT (PWM) | `SERVO_EYE_PAN` | SG90/MG90S signal | |
| 6 | OUT (PWM) | `SERVO_EYE_TILT` | SG90/MG90S signal | Omit if `USE_EYE_TILT 0`. |
| 7 | OUT (PWM) | `SERVO_FINGER` | SG90/MG90S signal | The finger. |
| 8 | I/O | `I2C_SDA` | VL53L0X ×2, SSD1306 | 4.7 kΩ pull-up to 3V3. Most breakouts already have one — do not stack four of them. |
| 9 | OUT | `I2C_SCL` | VL53L0X ×2, SSD1306 | 4.7 kΩ pull-up to 3V3. |
| 10 | IN pull-up | `LIMIT_CLOSED` | Lid closed microswitch → GND | Active LOW. Wire to the **NC-to-GND** contact so a broken wire reads "not closed" and faults safe. |
| 11 | IN pull-up | `LIMIT_OPEN` | Lid open microswitch → GND | Active LOW. |
| 12 | IN pull-up | `SWITCH_NORMAL` | NORMAL MODE latching switch → GND | Active LOW = ON. |
| 13 | IN pull-up | `HIDDEN_TRIGGER` | Concealed demo-rescue button → GND | Active LOW. See `HACKATHON_DEMO.md` §5. |
| 14 | IN pull-up | `IR_THROAT` | IR break-beam receiver / proximity module OUT | Active LOW = blocked. Optional (`USE_IR_THROAT`). |
| 15 | OUT (PWM) | `SERVO_FINGER_DOOR` | SG90 signal | The hatch. |
| 16 | OUT | `LED_DATA` | WS2812B DIN | Through 330 Ω, as close to the first pixel as possible. |
| 17 | OUT | `I2S_BCLK` | MAX98357A BCLK | Shared with DFPlayer TX if `AUDIO_BACKEND = AUDIO_DFPLAYER`. |
| 18 | OUT | `I2S_LRCLK` | MAX98357A LRC | Shared with DFPlayer RX in the DFPlayer build. |
| 21 | OUT | `I2S_DOUT` | MAX98357A DIN | |
| 38 | OUT | `SERVO_POWER_EN` | P-FET gate driver / relay coil driver | **HIGH = servo rail live.** Firmware pulls it LOW on `Lid::emergencyStop()`. Defaults LOW at reset, which is the safe state. |
| 47 | OUT | `TOF_THROAT_XSHUT` | VL53L0X #1 XSHUT | Held LOW at boot, then released to re-address to 0x30. |
| 48 | OUT | `TOF_APPROACH_XSHUT` | VL53L0X #2 XSHUT | Released second, re-addressed to 0x31. |

### 1.3 I²C address map

| Address | Device | Set by |
|---|---|---|
| 0x29 | VL53L0X (factory default) | Transient only — both sensors are moved off it at boot. |
| 0x30 | VL53L0X — throat | `Sensors::begin()` |
| 0x31 | VL53L0X — approach | `Sensors::begin()` |
| 0x3C | SSD1306 OLED | Module solder jumper. If yours is 0x3D, change `OLED_ADDR` in `display.cpp`. |

The XSHUT sequencing matters: both sensors boot at 0x29, so they are held in
reset, brought up one at a time and re-addressed. If XSHUT is left floating
the second sensor will never be found, and `healthSummary()` reports
`PARTIAL`.

---

## 2. Remote — ESP32-C3 SuperMini

### 2.1 Pins you must treat carefully

| GPIO | Why |
|---|---|
| 2 | Strapping — must be HIGH at reset. **Left unused.** |
| 8 | Strapping — must be HIGH at reset. Used only for the onboard status LED (output, idles as the LED driver wants). |
| 9 | Strapping — LOW at reset enters download mode. Used as the SECRET button. Do not hold it while resetting. |
| 20, 21 | UART0 RX/TX. Free here **only because the build logs over native USB CDC** — you must set *USB CDC On Boot = Enabled*. |

### 2.2 Assignments

| GPIO | Direction | Function | Command sent |
|---:|---|---|---|
| 0 | IN pull-up | Button — UP | `CMD_UP` |
| 1 | IN pull-up | Button — DOWN | `CMD_DOWN` |
| 3 | IN pull-up | Button — LEFT | `CMD_LEFT` |
| 4 | IN (ADC1_CH4) | **Aux resistor ladder**, 8 buttons | see below |
| 5 | I/O | I²C SDA — OLED | — |
| 6 | OUT | I²C SCL — OLED | — |
| 7 | IN pull-up | Button — RIGHT | `CMD_RIGHT` |
| 8 | OUT | Onboard status LED (WS2812 on most boards) | — |
| 9 | IN pull-up | BOOT button — SECRET | `CMD_SECRET` |
| 10 | IN pull-up | Button — OK | `CMD_OK` |
| 20 | IN pull-up | Button — OPEN | `CMD_OPEN` |
| 21 | IN pull-up | Button — CLOSE | `CMD_CLOSE` |

### 2.3 Aux button ladder

Eight buttons on one ADC pin. 10 kΩ pull-up to 3V3; each button pulls the node
to GND through a different resistor.

```
3V3 ──[10k]──┬── GPIO4 (ADC1_CH4)
             ├──[   0R ]──o/o── GND   AI
             ├──[   1k ]──o/o── GND   ANGRY
             ├──[ 2.2k ]──o/o── GND   MOOD
             ├──[ 4.7k ]──o/o── GND   STOP
             ├──[  10k ]──o/o── GND   NORMAL
             ├──[  22k ]──o/o── GND   MUTE
             ├──[  47k ]──o/o── GND   LIGHT
             └──[ 100k ]──o/o── GND   DARK
```

| Button | R to GND | V at node | Expected ADC (12-bit, 11 dB) |
|---|---:|---:|---:|
| AI | 0 Ω | 0.00 V | ~40 |
| ANGRY | 1 kΩ | 0.30 V | ~372 |
| MOOD | 2.2 kΩ | 0.60 V | ~738 |
| STOP | 4.7 kΩ | 1.06 V | ~1309 |
| NORMAL | 10 kΩ | 1.65 V | ~2048 |
| MUTE | 22 kΩ | 2.27 V | ~2816 |
| LIGHT | 47 kΩ | 2.72 V | ~3377 |
| DARK | 100 kΩ | 3.00 V | ~3723 |
| *(none)* | ∞ | 3.30 V | ~4095 |

ADC1 on the C3 is not especially linear near the rails, so **measure your own
values**: set `CALIBRATE_LADDER 1` in `pins.h`, flash, open the serial
monitor, press each button, and paste the readings into `LADDER_CENTERS`.
`LADDER_WINDOW` (±140 counts) is the accept band around each centre; readings
between bands decode as "nothing pressed", which is also what you get when two
buttons are pressed at once.

---

## 3. Quick continuity checklist

Before first power-on, with the supply disconnected:

- [ ] No continuity between 5 V and GND anywhere.
- [ ] No continuity between 3V3 and GND.
- [ ] Every servo ground returns to the star ground point, not through the ESP32 board.
- [ ] SDA and SCL each read ~4.7 kΩ to 3V3 and open to GND.
- [ ] Both limit switches read open at rest and short to GND when pressed.
- [ ] GPIO38 gate driver holds the servo rail **off** with the ESP32 unpowered.

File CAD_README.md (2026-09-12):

# CAD

All 24 custom parts, as parametric OpenSCAD.

Open <https://openscad.org/> — or render from the command line:

```bash
openscad -o lid_frame.stl -D 'part="lid_frame"' cad/lid_mechanism.scad
```

`cad/binchad_params.scad` holds every shared dimension. Change a number there
and every part that references it follows. That is the entire point: the lid
width appears in the hinge, the servo mount, the linkage length and the body
cut-out, and they must not be allowed to disagree.

Exploded assembly

---

## 1. The torque budget

**Do this sum before you buy a servo. Do it again if you change the lid.**

```
tau_static = m · g · d · cos(theta)          worst case at theta = 0 (lid horizontal)

    m  = lid mass, including hinge hardware ........ 0.180 kg   ← WEIGH YOURS
    g  = 9.81 m/s²
    d  = hinge axis to centre of gravity ........... 0.110 m

tau_static = 0.180 × 9.81 × 0.110 = 0.194 N·m = 1.98 kgf·cm

required   = tau_static × safety factor (2.0) = 3.96 kgf·cm
fitted     = MG996R @ 5 V = 9.4 kgf·cm

margin     = 4.7 ×
```

The margin is generous on purpose. It covers a stiff hinge, a cold servo, a
sagging 5 V rail, and somebody resting a hand on the lid.

**If your lid is heavier**, recompute and move up: DS3218 is 20 kgf·cm, DS3225
is 25. **Do not fit an SG90** (1.8 kgf·cm) and hope. It will not lift the lid,
it will strip its own gears trying, and it will do so during the demo.

The ribbed `lid_frame` exists to keep `m` down. A solid 5 mm lid of the same
footprint is over 400 g, needs 4.4 kgf·cm static, and would push you to a
DS3218 and a bigger power supply for no benefit.

### Where the servo actually sits

The design uses a **two-bar linkage**, not a servo horn bolted to the hinge.
That puts the servo low in the body (better mass distribution, shorter power
run) and lets you trim the effective lever arm on assembly by moving the
linkage anchor. `link_len` is 62 mm nominal — expect to adjust it once. The
slotted holes in `servo_mount` exist for exactly this.

---

## 2. Part index

### `lid_mechanism.scad`

| `part=` | Qty | Material | Notes |
|---|---:|---|---|
| `hinge_body` | 2 | PETG | Carries the full lid load. 4 perimeters, 40 % infill minimum. |
| `hinge_lid` | 2 | PETG | Same. |
| `lid_frame` | 1 | PLA or PETG | Print **top-face-down**. No supports. |
| `servo_mount` | 1 | PETG | Slotted holes for linkage trimming. |
| `linkage` | 1 | PETG | **100 % infill.** 4 mm thick, carries the whole lid load. |
| `lid_stop` | 2 | PETG | Hard end stop. Firmware bugs cannot drive past it. |
| `lid_stop_pad` | 2 | **TPU** | The bumper that stops the clack. |

### `finger_module.scad`

| `part=` | Qty | Material | Notes |
|---|---:|---|---|
| `box` | 1 | PETG | Print open-face-down. |
| `door` | 1 | PLA | The hatch. |
| `finger` | 1 | PLA | Oversized on purpose. |
| `finger_tip` | 1 | **TPU** | Soft contact with the switch — see §3. |
| `servo_plate` | 1 | PETG | Carries both micro servos. |
| `faceplate` | 1 | PLA | Recessed label panel for an inlay or sticker. |

### `eye_and_sensors.scad`

| `part=` | Qty | Material | Notes |
|---|---:|---|---|
| `eye_ball` | 1 | PLA, **matte** | Back is flattened so it prints without supports. |
| `eye_lens` | 1 | **clear PETG**, 3 perimeters, 0 % infill | Or buy a 26 mm acrylic dome. |
| `eye_yoke` | 1 | PETG | Tilt axis. |
| `eye_pan_base` | 1 | PETG | Pan servo cradle. |
| `tof_bracket` | 2 | PLA | 4 mm standoff — see §3. |
| `oled_bezel` | 1 | PLA | |

### `chassis_and_tray.scad`

| `part=` | Qty | Material | Notes |
|---|---:|---|---|
| `tray` | 1 | PETG | ESP32-S3 hole pattern + 10 mm utility grid. |
| `tray_rails` | 2 | PETG | The tray slides out on these. |
| `button_plate` | 1 | PETG | NORMAL MODE switch. Includes a finger-reach witness mark. |
| `service_panel` | 1 | PLA | Rear access, with a USB-C cut-out so you can reflash without opening. |
| `foot` | 4 | **TPU**, 30 % infill | Should squash a little. |
| `led_diffuser` | 1 | clear/white PLA | Channel for a 10 mm WS2812 strip. |
| `speaker_grille` | 1 | PLA | |

### `remote_enclosure.scad`

| `part=` | Qty | Material | Notes |
|---|---:|---|---|
| `shell` | 1 | PLA | 190 × 110 × 34 mm. Deliberately too big for one hand. |
| `faceplate` | 1 | PLA | All button holes + recessed label panels. |
| `cap_round` | 7 | PLA | D-pad, OK, OPEN, CLOSE. |
| `cap_danger` | 1 | **red** PLA | Does nothing useful. Essential. |
| `antenna` | 1 | PLA | Electrically inert. The C3's real antenna is a PCB trace. |
| `battery_door` | 1 | PLA | |

**24 distinct parts, 33 pieces total.**

---

## 3. Three details that matter more than they look

**The ToF standoff.** `tof_bracket` holds the VL53L0X 4 mm proud of the
mounting face, with a window wider than the PCB. A bracket that shadows the
emitter is the single most common cause of *"the sensor reads 8190 forever"*.
Do not close that window up to look neater.

**The TPU finger tip.** At `FINGER_ANGLE_PRESS` (112°) the tip lands roughly
6 mm **past** the switch face. The overshoot is deliberate: it guarantees the
switch is fully thrown even with assembly slop. The TPU absorbs it, so the
servo stalls softly instead of stripping its gears on a switch that has already
bottomed out. Print the tip soft, and do not substitute rigid plastic.

**The finger-reach witness mark.** `button_plate` prints a 0.4 mm proud ring
showing where the finger tip should land. Check it during dry assembly
(`BUILD_GUIDE.md` §5), then sand it off. `finger_reach = finger_len + 6` in the
SCAD source is the number to verify against your actual geometry.

---

## 4. Print settings

| | Structural (PETG) | Cosmetic (PLA) | Soft (TPU) |
|---|---|---|---|
| Layer height | 0.20 mm | 0.20 mm | 0.20 mm |
| Perimeters | 4 | 3 | 3 |
| Infill | 40 % gyroid | 20 % gyroid | 30 % gyroid |
| Supports | only `eye_yoke` | none | none |
| Nozzle | 0.4 mm | 0.4 mm | 0.4 mm |
| Speed | 45 mm/s | 60 mm/s | 20 mm/s |

Exceptions: `linkage` at 100 % infill. `hinge_body` / `hinge_lid` at 40 %
minimum — they carry the lid.

**Total print time** for the full set is roughly 34 hours and about 620 g of
filament. The `lid_frame` alone is ~9 hours; start it first.

### Tolerances

`binchad_params.scad` defines three fits, all measured on a stock
Ender-class printer:

```
fit_snug  = 0.15   press fit — a pin in a bracket
fit_loose = 0.35   free rotation — the hinge pin in its bore
fit_clear = 0.60   a panel in a slot, a cable through a hole
```

If your holes come out tight, **raise `fit_loose`** — do not scale whole
parts, which throws off every screw hole simultaneously.

---

## 5. Serviceability rules

These are design constraints, not suggestions. They are why the machine is
fixable at 3 a.m. with ten minutes to go.

- **Heat-set inserts everywhere a screw enters plastic more than once.**
  M3 × 5.0 mm brass. `insert_boss()` prints the bore undersize on purpose —
  the brass melts its own interference fit.
- **Nothing is glued.** Not the electronics, not the sensors, not the eye.
- **The electronics tray slides out of the back** with the loom still
  attached, on `tray_rails`.
- **The lid lifts off** by pulling one 4 mm hinge pin. No disassembly of
  anything else.
- **The finger cartridge is four screws** and one connector. It is the part
  most likely to be broken by an enthusiastic audience, so it is the part
  designed to be swapped fastest — print a spare.
- **The service panel has a USB-C cut-out.** You can reflash without opening
  the bin.

---

## 6. Retrofitting a bought bin

The reference build wraps a 210 × 210 mm square opening. To fit yours:

1. Measure the opening. Set `bin_opening_x`, `bin_opening_y`.
2. Set `lid_x` / `lid_y` to opening + 4 mm overhang.
3. **Weigh the lid you end up with**, set `lid_mass_g`, and balance it on a
   ruler to find `lid_cog_mm`.
4. Redo the torque sum in §1. Confirm your servo still has ≥ 2× margin.
5. Set `hinge_span` to something your lid can actually support — roughly
   70 % of the lid width.
6. Re-render everything. Dry-fit before you print the second copy of anything.

Round bins work too, but you will need to replace the collar profile; the
hinge, servo mount, linkage and finger cartridge are all independent of the
body shape.

---

## 7. Safety constraints baked into the geometry

- **No sharp edges anywhere a user can reach.** The finger tip is a TPU
  sphere. The faceplate and lid edges are chamfered or filleted.
- **Hard mechanical stops at both ends of lid travel** (`lid_stop`), so a
  firmware fault cannot drive the lid into the body or past vertical.
- **The finger is low-torque by design** — an SG90 at 1.8 kgf·cm on a 58 mm
  arm cannot generate a pinch force that matters, and it stalls harmlessly.
- **No projectiles, no blades, no heating elements, no mains voltage inside
  the enclosure.** The only mains connection is a sealed, certified PSU.

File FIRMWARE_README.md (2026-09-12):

# FIRMWARE

Two sketches, one shared protocol header, no external state.

State machine

---

## 1. Toolchain

| | Bin | Remote |
|---|---|---|
| Sketch | `firmware/BinChad/BinChad.ino` | `firmware/BinRemote/BinRemote.ino` |
| Board | ESP32S3 Dev Module | ESP32C3 Dev Module |
| Core | Arduino-ESP32 **3.x** | Arduino-ESP32 **3.x** |
| USB CDC On Boot | **Enabled** | **Enabled** (mandatory — GPIO20/21 are buttons) |
| Flash size | match your module (8/16 MB) | 4 MB |
| Partition | any scheme with a SPIFFS/LittleFS partition | default |
| PSRAM | match your module (OPI for N16R8) | — |

Arduino-ESP32 core: <https://github.com/espressif/arduino-esp32>
Reference docs: <https://docs.espressif.com/projects/arduino-esp32/en/latest/>

### Libraries

| Library | Used for | Source |
|---|---|---|
| ESP32Servo | All five servos | <https://github.com/madhephaestus/ESP32Servo> |
| Adafruit VL53L0X | Both ToF sensors | <https://github.com/adafruit/Adafruit_VL53L0X> |
| Adafruit SSD1306 | OLED | <https://github.com/adafruit/Adafruit_SSD1306> |
| Adafruit GFX | OLED primitives | <https://github.com/adafruit/Adafruit-GFX-Library> |
| Adafruit NeoPixel | WS2812B | <https://github.com/adafruit/Adafruit_NeoPixel> |
| ESP_I2S | I²S audio (built into core 3.x) | part of Arduino-ESP32 |
| esp_now | Remote link (built into core) | <https://developer.espressif.com/blog/2024/08/arduino-esp-now-lib/> |

All are actively maintained. `LittleFS`, `WiFi`, `Wire` and `esp_now` ship with
the core.

> **Core 2.x users:** the ESP-NOW receive callback signature and `ESP_I2S.h`
> both changed in core 3.0. The firmware detects this
> (`ESP_ARDUINO_VERSION_MAJOR`, `__has_include`) and still compiles, but audio
> falls back to silent. Set `AUDIO_BACKEND` to `AUDIO_DFPLAYER` if you are
> stuck on 2.x and want sound.

### Uploading the sound files

The I²S build streams 16-bit mono WAV files from LittleFS.

```bash
python tools/make_wavs.py          # writes placeholder clips to firmware/BinChad/data/
```

Then in Arduino IDE: **Tools → ESP32 Sketch Data Upload**
(install <https://github.com/lorol/arduino-esp32fs-plugin> first), or:

```bash
arduino-cli ... --build-property build.partitions=default
mklittlefs -c firmware/BinChad/data -s 1572864 littlefs.bin
esptool.py --chip esp32s3 write_flash 0x290000 littlefs.bin   # check YOUR partition offset
```

Replace the placeholders with real recordings whenever you like — same
filenames, 16-bit mono PCM, 22 050 Hz, **under one second each**. A missing
file is not an error; that clip is simply silent.

---

## 2. Module map

```
firmware/BinChad/
  BinChad.ino                 setup() + loop(). Calls update() on everything, every pass.
  data/                       WAV clips -> LittleFS
  src/
    config/
      pins.h                  GPIO map. Also documents the pins you must not use.
      settings.h              EVERY tunable number. Timings, angles, thresholds, weights.
    hardware/
      sensors.{h,cpp}         Dual VL53L0X + debounced switches. Degrades, never dies.
      lid.{h,cpp}             Eased motion, obstruction abort, limit-switch verification.
      eye.{h,cpp}             Pan/tilt saccades, blink, jitter, sleep.
      uselessFinger.{h,cpp}   The hatch + finger sequence, with press verification.
      leds.{h,cpp}            Eleven WS2812 patterns, frame-driven.
      audio.{h,cpp}           I2S WAV streaming / DFPlayer / silent. Chunked, non-blocking.
    ui/
      display.{h,cpp}         SSD1306 face, text, progress bar, self-test screen.
    remote/
      protocol.h              SHARED with the remote. Packet structs + checksum.
      remote.{h,cpp}          ESP-NOW receive, ring buffer, de-duplication, ACK.
    personality/
      personality.{h,cpp}     Mood machine, counters, escalation, lines, mistranslation.
    behavior/
      behaviorManager.{h,cpp} The top-level state machine. The ONLY module that commands hardware.
```

### The two architectural rules

**1. One actuation site.** `behaviorManager.cpp` is the only file that calls
`lid.open()`, `finger.deploy()`, and so on. Sensors sense, personality decides,
behaviour acts. This is what makes the safety argument tractable: there is
exactly one file to audit for *"what can make the lid move"*.

**2. Nothing blocks.** No `delay()` after `setup()`. Every module exposes
`begin()` and `update()`, and `update()` does at most one step of work before
returning. If you add a `delay()` to `loop()`, the lid stops checking for
fingers for that long, which is the one thing it must never do.

---

## 3. How a throw is processed

```
sensors.update()          ToF sample -> hysteresis -> objectInThroat edge
        ↓
behavior.handleSensors()  IDLE + person -> CURIOUS ("OH NO.")
        ↓                 CURIOUS + object -> startThrowResponse()
        ↓
startThrowResponse()      eye looks into the bin, lid.holdOpenFor(3000),
                          LEDs to ALERT, "TRASH DETECTED", enter ST_THROW_WAIT
        ↓
ST_THROW_WAIT             _throatWasBlocked latches when the object passes the beam.
                          Blocked -> then clear  = it went in       -> reactSuccess()
                          2.6 s with no block    = you missed       -> reactMiss()
                          hidden trigger pressed = it went in, honestly -> reactSuccess()
        ↓
reactMiss()               lid closes, eye locks onto the thrower, LEDs idle,
                          and then NOTHING happens for two full seconds
        ↓
ST_MISS_SILENCE (2000 ms) the pause is the joke. Resist shortening it.
        ↓
ST_MISS_REACT             personality.missLine(), SND_MISS, red flash
```

Success is detected as **blocked → clear**, not merely "something is close".
A hand held over the opening blocks the beam without ever clearing it, so it
reads as neither a success nor a miss — which is correct.

---

## 4. Safety implementation

Three independent mechanisms, in order of how fast they act:

| Layer | Where | Response |
|---|---|---|
| Obstruction abort | `Lid::update()`, first statement | Checked before any motion step on every loop pass. Stops the close, reverses to open, sets an event flag. |
| Endpoint verification | `Lid::finishMove()` | The servo claims it arrived; the limit switch decides. Disagreement for `LID_LIMIT_TIMEOUT_MS` raises `LID_ERROR` and detaches the servo rather than grinding. |
| Rail cutoff | `Lid::emergencyStop()`, GPIO38 | Drops the servo supply entirely. Default state at reset is **off**. |

Plus the motion profile itself: `ease()` is a cosine ease-in-out with zero
velocity at both endpoints, and `LID_MS_CLOSE` (900 ms) is more than twice
`LID_MS_OPEN` (380 ms). Even `LID_SPEED_ANGRY` runs through the same easing and
the same obstruction check — angry is 220 ms of *eased* travel, not a slam.

The hand-detect input is deliberately **OR-ed** across the ToF and the IR beam
(`Sensors::handInDangerZone()`). If either channel thinks there is a hand in
there, there is a hand in there. Comedy does not get a vote on that function.

After `LID_MAX_RETRIES` blocked closes, the lid gives up and stays **open**.
Failing open is the safe direction for a lid.

---

## 5. The personality engine

`personality.cpp` owns the mood state machine, five counters, and the line
tables. It commands no hardware.

**Escalation** is driven by `missCount` and an `anger` accumulator (0–100,
+14 per miss, −1 every 1.5 s, halved by an obstruction because the bin feels
genuinely bad about that one):

| Trigger | Result |
|---|---|
| 1st–2nd miss | Standard line: *"You missed." / "Almost."* |
| 3rd miss (`MISS_ANNOY_AT`) | 55 % chance of the annoyed table: *"Again?"* |
| 5th miss (`MISS_CONCERN_AT`) | State → `P_SARCASTIC` |
| 10th miss (`MISS_ANGRY_AT`) or anger ≥ 85 | State → `P_ANGRY`: red strobe, narrowed eye, *"ENOUGH."* |
| 20 s in ANGRY with anger < 40 | Cools back to IDLE |

**Determinism.** Line choice and mistranslation both come from a seeded
xorshift32 (`Personality::rnd()`), not `rand()`. The seed is derived from the
board's MAC, so it is stable across reboots of the same board and different
between two bins in the same room. A given demo replays identically, and a bug
is reproducible. `pick()` additionally never returns the same line twice
consecutively.

---

## 6. Tuning

Everything worth changing is in `src/config/settings.h`. The values you will
actually touch:

| Symbol | Default | Change it when |
|---|---:|---|
| `LID_ANGLE_CLOSED` / `LID_ANGLE_OPEN` | 12 / 96 | Always — these are per-build. See `BUILD_GUIDE.md` §7.1. |
| `LID_INVERT` | false | Your linkage mirrors the reference. |
| `LID_MS_CLOSE` | 900 | The close feels rushed, or too slow to be funny. |
| `TOF_THROAT_OBJECT_MM` | 200 | Your bin's throat is deeper/shallower than 260 mm. |
| `SAFETY_HAND_MM` | 130 | **Rarely.** Raising it makes the lid more cautious; lowering it makes it less safe. |
| `THROW_WINDOW_MS` | 2600 | People are throwing from further away. |
| `MISS_SILENCE_MS` | 2000 | Never. Two seconds is correct. |
| `SLEEP_AFTER_MS` | 90 000 | The bin naps during your demo. |
| `LED_BRIGHTNESS` | 90 | The venue is bright, or your 5 V rail is sagging. |
| `AUDIO_VOLUME_DEFAULT` | 18 | The room is loud. |

Compile-time switches at the top of the same file: `AUDIO_BACKEND`,
`USE_EYE_TILT`, `USE_TOF_APPROACH`, `USE_IR_THROAT`, `USE_NORMAL_LAMP`. All
five can be turned off and the machine still runs — useful for staged bring-up.

---

## 7. Debugging

The serial console prints a heartbeat every 5 s:

```
[hb] IDLE/IDLE lid=0 ang=0 frus=0 thr=8190mm app=1240mm cyc=37 rx=412
      │    │     │      │      │      │           │          │     └ ESP-NOW packets accepted
      │    │     │      │      │      │           │          └ lid open/close cycles
      │    │     │      │      │      │           └ approach ToF (8190 = out of range)
      │    │     │      │      │      └ throat ToF
      │    │     │      │      └ remote frustration 0..12
      │    │     │      └ anger 0..100
      │    │     └ LidState enum
      │    └ PersonalityState
      └ MainState
```

A frozen heartbeat means a hung `loop()`. A heartbeat that keeps ticking while
nothing moves means a hung mechanism — which is a much better problem to have
at 3 a.m., and is exactly why the heartbeat exists.

Other useful lines: `[remote] asked OPEN -> doing CLOSE`,
`[lid] obstruction detected - aborting close`,
`[lid] endpoint 96 not confirmed by limit switch`,
`[sensors] THROAT ToF did not answer`.

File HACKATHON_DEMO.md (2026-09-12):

# HACKATHON DEMO

Two minutes. Four beats. One punchline.

The rule that governs everything below: **the audience must understand the
joke without your explanation.** If you have to narrate what the bin is doing,
the machine has failed, not the script. Talk less than you think you should.

---

## 1. Setup, before they arrive

| | |
|---|---|
| Bin position | Chest height if possible, on a stable table, lid clear |
| Your position | Beside the bin, hidden trigger within reach |
| Throwables | 3–4 light, soft, bin-sized items. Paper balls are ideal — a crumpled sheet is visible, harmless, and forgiving |
| Remote | On the table, in view, **not** in your hand yet |
| Power | Wall socket, not a battery. Cable taped down |
| Volume | Set for the actual room, with people in it |
| State | **Reboot immediately before.** Fresh miss counter, zero frustration |

That last one matters. If you have been testing all morning, the bin is
already at maximum frustration and will never obey — which kills beat 3,
where the audience needs to see it *sometimes* comply so they understand it is
choosing not to.

---

## 2. The script

### Beat 1 — It notices you (0:00–0:25)

**Walk toward the bin. Say nothing.**

The eye turns to follow you. The LEDs pulse. The display reads `OH NO.`

Let that sit for two seconds before you do anything. The whole premise lands
here, silently, and every second you do not speak makes it land harder.

**Throw the first item in.**

Lid opens, object goes in, green sweep, *"Acceptable."*

> First laugh. You have said nothing at all so far.

---

### Beat 2 — It has opinions (0:25–0:55)

**Throw the second item, deliberately missing.**

Lid opens. Nothing goes in. Lid closes.

Then: **nothing happens for two full seconds.** The eye is locked on you. No
sound, no lights, no movement.

Then: *"My grandmother throws better."*

> The silence is the joke. Do not fill it. Do not look at the audience. Look
> at the bin, the way you would look at a colleague who has just said
> something rude.

**Throw a third, and miss again.**

*"Again?"* — the escalation is visible, and the audience now understands the
machine is keeping score.

---

### Beat 3 — The remote (0:55–1:30)

**Pick up the remote. Show it to the room.** It is absurdly large, it has an
antenna, and it says **PLEASE DO NOT TRUST.**

Press **OPEN**. → The lid closes.

Look at the remote. Press **CLOSE**. → The lid opens.

> Second big laugh. Still no explanation from you.

Press **STOP**. → Everything speeds up. The display says `FASTER`.

Press **AI**. → `CALIBRATING USER…` climbs, stalls at 99 %, and delivers
`RESULT: YOU SHOULD THROW BETTER.` Then it does something completely
unrelated.

Put the remote down with visible disappointment.

---

### Beat 4 — The punchline (1:30–2:00)

**Point at the big illuminated button. Say the only line you need:**

> "There's a normal mode."

**Press it.**

The lights go clean white. The display says `NORMAL MODE ACTIVATED`. Throw
something in — the lid opens and closes properly, politely, like an ordinary
automatic bin.

**Now stop talking and take one step back.**

- The eye turns, slowly, to look at the button.
- Nothing happens for a moment.
- A hatch opens in the front panel.
- **Nothing happens for another moment.**
- An enormous finger extends, flips the switch off, and retracts.
- The hatch closes.
- Display: **`NORMAL MODE CANCELLED`**

> That is the end of the demo. Do not add anything. Let them react, then stop.

---

## 3. Timing notes

The two pauses — the 900 ms before the hatch opens, and the 900 ms before the
finger comes out — are the most important numbers in the firmware
(`FINGER_PAUSE_MS`). They are what turn a mechanism into a joke. If the
punchline is not landing in rehearsal, lengthen them before you change
anything else.

`NORMAL_MODE_GRACE_MS` (4.5 s) is the second-most important. Long enough that
the audience believes the bin has genuinely reformed; short enough that they
have not lost interest.

---

## 4. What to say, and what not to

**Say:**
- "There's a normal mode." (one line, beat 4)
- Nothing else, unless asked.

**Do not say:**
- "So what's happening here is…"
- "It's using a time-of-flight sensor to…"
- "Wait, it normally works…"

Save the engineering for questions. When they come, you have:

- The torque budget and why the lid cannot slam (`CAD_README.md` §1)
- Two independent hand-detection channels, OR-ed (`FIRMWARE_README.md` §4)
- The deterministic mistranslation engine — *"it's not random, it's
  deliberate, here are the probability tables"* (`REMOTE_PROTOCOL.md` §5)
- ESP-NOW, so it works with the venue Wi-Fi switched off

The contrast between the seriousness of those answers and the stupidity of the
machine is itself the pitch.

---

## 5. Failure-proofing

### The hidden trigger

A concealed button on GPIO13 fires a **complete, indistinguishable success
reaction**: lid closes, green sweep, approving line, counters incremented.

Use it when a throw misses and you needed it to land. Nobody can tell.

**Rules:**
- Mount it where your hand naturally rests. Do not reach for it obviously.
- Press it *while the object is still in the air*, not after it has bounced
  off the rim.
- It also clears a `LID ERROR` — see `TROUBLESHOOTING.md` §6.
- Never mention it. Not in the demo, not in the Q&A, not in the README you
  show the judges. (It is documented here because your own team needs to know.)

### If something breaks mid-demo

The machine is designed so no single failure kills the show:

| Broken | What you do |
|---|---|
| Lid | Skip to the remote and the punchline. Both still work. |
| Sensors | Hidden trigger. Nothing visibly changes. |
| Remote | The bin's own behaviour and the NORMAL MODE punchline carry it. |
| Audio | Everything is also on the display. Turn and read it aloud, deadpan. |
| Finger | This is the one that hurts. Swap the spare cartridge (four screws) if you have time; otherwise end on the remote and describe the finger. |
| Everything | *"It has decided not to cooperate today."* That is genuinely on-brand, and the honest fallback beats visible panic. |

Keep on the table: a spare finger cartridge, a spare USB-C cable, a laptop
that can reflash, and spare paper balls.

---

## 6. Handling the obvious questions

**"Is it actually doing AI?"**
No, and the firmware never claims otherwise anywhere a user can see. `AI MODE`
is a progress bar with opinions. If we had put a model on it we would have
documented the model and the inference pipeline. Answer this one honestly and
immediately — a project that fakes an AI claim loses the room, and *"no, it's
a progress bar, that's the joke"* gets a laugh.

**"Is it safe?"**
Yes, and here is the test log. Two independent sensors watch the closing zone,
either one stops and reverses the lid, the motion is cosine-eased so it cannot
slam, hard mechanical stops limit travel, and the servo rail defaults to off
at reset. `TEST_PLAN.md` §2 is 13 tests and they all pass.

**"How long did this take?"**
Longer than it should have. That is the point.

**"Why?"**
Because we could build it.

---

## 7. Sixty-second version

If you get cut short, drop beats 1 and 2 entirely:

1. Throw something in. It works. (10 s)
2. Remote: OPEN closes, CLOSE opens. (20 s)
3. "There's a normal mode." Press it. Wait. Finger. (30 s)

The punchline is the demo. Everything before it is setup, and setup is what
you cut.

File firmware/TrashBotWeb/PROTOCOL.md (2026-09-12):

# WEBSOCKET PROTOCOL

Link between a browser and **TRASHBOT OS**.

| | |
|---|---|
| Transport | WebSocket, `ws://<host>/ws` |
| Encoding | JSON, UTF-8, one message per frame |
| Frame limit | 512 bytes inbound — anything larger is refused without being parsed |
| Fragmentation | Not supported. Every message this protocol defines fits in one frame. |
| Clients | Up to 4 at once. They all see the same telemetry and the same log. |

Chosen over HTTP polling because the dashboard needs sub-100 ms feedback in
both directions, and because a persistent connection is itself the liveness
signal the safety layer uses: if the socket drops, the motors stop.

Messages arriving on the socket are handled in the AsyncTCP task, which
validates them and pushes a fixed-size struct into a ring buffer. Nothing
acts on a command outside `loop()`. The one exception is `estop`, which
latches the moment it is parsed.

---

## 1. Browser → bin

Every message has a `type`. Unknown types are dropped in silence; malformed
JSON is dropped and logged as `COMMAND_REJECTED`. Every field is bounded on
arrival — there is no path by which a browser can ask for a duty above the
configured ceiling.

### 1.1 `ping`

```json
{ "type": "ping", "snd": true }
```

Sent every 400 ms. Any inbound message refreshes the link timer, so a stream
of `drive` messages serves the same purpose; the ping exists so that an idle
browser still counts as present.

`snd` is true when that browser has unlocked audio playback. It is the only
way the bin can know it has a speaker; `telemetry.audioReady` reflects it for
10 s after the last such ping.

**Contract:** 1500 ms with no inbound message of any kind is a link timeout
and cuts the motors.

### 1.2 `drive`

Two forms. Discrete, from the D-pad:

```json
{ "type": "drive", "dir": "forward", "speed": 60 }
```

Analogue, from the joystick:

```json
{ "type": "drive", "x": -42, "y": 88, "speed": 60 }
```

| Field | Range | Notes |
|---|---|---|
| `dir` | see below | Takes precedence over `x`/`y` if present. |
| `x`, `y` | −100..100 | `y` is positive forward. Quantised to one of eight sectors. |
| `speed` | 0..100 | Percent. In the analogue form it is scaled by stick deflection. |

Direction wire names:

```
stop  forward  backward  left  right
fwd_left  fwd_right  back_left  back_right
```

A vector with a magnitude under 20 is a `stop`.

**Contract:** repeat every 100 ms while the control is held, and send
`{"type":"drive","dir":"stop"}` on release. 450 ms without drive intent
ramps the motors to zero. A `stop` also cancels any command still waiting out
its delay.

### 1.3 `action`

```json
{ "type": "action", "action": "please" }
```

One of `open`, `close`, `please`, `sorry`, `panic`, `do_nothing`,
`normal_mode`.

### 1.4 `mode`

```json
{ "type": "mode", "mode": "chaos" }
```

One of `normal`, `uncooperative`, `reverse`, `chaos`, `drunk`, `lazy`,
`angry`, `panic`, `sleep`. Changing mode cancels any pending delayed command.

### 1.5 `speed`

```json
{ "type": "speed", "value": 60 }
```

The slider's resting value, clamped to 10..100. Sent on release rather than
during the drag. Individual `drive` messages carry their own `speed`.

### 1.6 `estop` and `reset_safety`

```json
{ "type": "estop" }
{ "type": "reset_safety" }
```

`estop` cuts the motors and latches, in the network task, before the main loop
runs again. No mode, mood or trait value can influence it.

`reset_safety` is the only thing that clears the latch. Nothing moves until a
fresh drive command arrives afterwards.

### 1.7 `cal_jog` and `cal_set`

```json
{ "type": "cal_jog", "motor": "left", "dir": "forward" }
{ "type": "cal_set", "field": "max_duty", "value": 200 }
```

`motor` is `left` or `right`; `dir` is `forward`, `reverse` or `stop`. A jog
runs one motor for at most 2000 ms and then stops itself. Jogs are refused
while the emergency stop is latched.

`cal_set` fields:

| Field | Range | Meaning |
|---|---|---|
| `left_invert` | 0/1 | Flip the left motor's direction. |
| `right_invert` | 0/1 | Flip the right motor's direction. |
| `max_duty` | 40..255 | Ceiling. Everything is clamped to this. |
| `min_duty` | 0..`max_duty`−1 | Non-zero requests are lifted to this. |
| `accel` | 1..60 | Duty change per 20 ms tick while speeding up. |
| `trim` | −20..20 | Straightness. Positive slows the left motor. |
| `save` | — | Commit the current values to NVS. |

Changes apply immediately and are lost on reboot until `save`.

### 1.8 `vision`

```json
{ "type": "vision", "persons": 1, "objects": "cup,bottle", "conf": 83, "src": "phone" }
```

A detection result from whoever ran the detector. `persons` 0..255,
`objects` a comma-separated list of class names (`person` is ignored here;
it is counted, not listed), `conf` 0..100 is the best score in the frame,
`src` is `phone` (this device's camera) or `cam` (ESP32-CAM snapshots).

Send on every change and at least once a second while running: a source
that is silent for 5 s is dropped. Send `persons: 0` when stopping rather
than letting it time out. The bin decides what is news — see §2.6 and the
README — and nothing in this message can move a motor.

### 1.9 `sound_test`

```json
{ "type": "sound_test", "event": "estop" }
```

Fire that event's clip on every link, cooldowns bypassed. The AUDIO tab's
TEST button. Logged as `AUDIO_TEST`; if nothing is assigned it says so.

---

## 2. Bin → browser

### 2.1 `hello`

Sent once per client, on connect.

```json
{
  "type": "hello",
  "version": "0.1.7",
  "seed": "0x9F3A1C22",
  "pingMs": 400,
  "driveRepeatMs": 100,
  "driveTimeoutMs": 450,
  "hw": {
    "esp32": "online", "l298n": "configured",
    "motorL": "configured", "motorR": "configured",
    "lid": "not_installed", "camera": "see_telemetry", "speaker": "see_telemetry",
    "ble": "online", "usb": "configured", "visionUart": "configured",
    "battery": "not_instrumented"
  },
  "ble": {
    "name": "TRASHBOT",
    "service": "7a5b0001-8e6f-4c1d-9b2a-3f4e5d6c7b8a",
    "sound":   "7a5b0002-8e6f-4c1d-9b2a-3f4e5d6c7b8a",
    "command": "7a5b0003-8e6f-4c1d-9b2a-3f4e5d6c7b8a"
  }
}
```

`hw` values are `online`, `configured`, `not_installed`, `not_instrumented`
or `see_telemetry`. **`online` is only used where the state is genuinely
observable.** Passive parts that cannot be sensed on these pins report
`configured`, meaning the firmware is driving those pins — not that anything
was detected. Nothing here is auto-detected. `see_telemetry` marks the two
parts the bin borrows from the phone (camera, speaker): whether a phone is
doing that job right now is observable and lives in `telemetry.vision` and
`telemetry.audioReady`. `ble` is `online` once advertising started,
`failed` if the radio did not come up, `not_installed` if compiled out.

The `ble` block is the GATT layout, so the browser does not hard-code it
(§4).

`seed` is the personality PRNG seed. Behaviour is reproducible for a given
seed.

### 2.2 `config`

Sent on connect and after any calibration change.

```json
{ "type": "config",
  "cal": { "left_invert": false, "right_invert": false,
           "max_duty": 200, "min_duty": 70, "accel": 12,
           "trim": 0, "duty_ceiling": 255 } }
```

### 2.3 `telemetry`

Broadcast at 10 Hz while at least one client is connected.

```json
{
  "type": "telemetry",
  "mode": "CHAOS", "mood": "ANGRY", "modeId": 3, "moodId": 4,
  "traits": { "anger": 82, "trust": 18, "happiness": 41,
              "confusion": 30, "boredom": 52, "obedience": 4,
              "rebellion": 91 },
  "leftMotor": -70, "rightMotor": 70,
  "leftTarget": -70, "rightTarget": 70,
  "speedReq": 60,
  "estop": false, "estopReason": "", "inhibit": "",
  "clients": 1, "uptime": 123456, "heap": 184320, "rssi": -54,
  "pendingCmd": false, "normalGrace": false, "jog": false,
  "lid": { "installed": false, "open": false, "simulated": true },
  "battery": null,
  "bleClients": 0,
  "vision": { "source": "phone", "live": true, "persons": 1, "present": true,
              "objects": "cup,bottle", "conf": 83, "humans": 3, "things": 7 },
  "audioReady": true
}
```

Motor values are percentages of the configured `max_duty`, signed. `Target`
is what was asked for; the unsuffixed value is where the ramp has actually
got to.

`inhibit` is why the motors are being held at zero, if they are:
`EMERGENCY STOP`, `NO CLIENT`, `LINK TIMEOUT`, or empty. `clients` counts
WebSocket browsers; `bleClients` counts Bluetooth phones. Both count for the
`NO CLIENT` rule.

**`battery` is `null` and stays `null`** until a divider exists to measure it.
A number here would be a fabricated sensor reading.

`vision` is the bin's own view of the last report: `source` is `phone`,
`cam`, `uart`, `http` or `none`; `live` false with a source name means that
source went quiet and the numbers are stale; `present` is the debounced
"someone is here" (a person must be gone 2.5 s to clear it); `humans` and
`things` are lifetime arrival counts. `audioReady` is whether any phone has
said it can play sound in the last 10 s.

### 2.4 `event`

One per log entry, plus a replay of the last 16 on connect.

```json
{ "type": "event", "seq": 412, "ms": 102341,
  "code": "COMMAND_MODIFIED", "text": "FORWARD -> BACKWARD (Because I can.)" }
```

`seq` is monotonic, so a client can tell whether it missed anything.

Codes in use:

```
BOOT                 NET_UP               NET_CONFIG
USER_CONNECTED       USER_DISCONNECTED    QUEUE_FULL
COMMAND_RECEIVED     COMMAND_EXECUTED     COMMAND_MODIFIED
COMMAND_REJECTED     COMMAND_CANCELLED    ACTION
SPEED_SET            MODE_CHANGED         MOOD_CHANGED
LID_OPENED           LID_CLOSED           PANIC
NORMAL_MODE          NORMAL_MODE_DISABLED
SAFETY_STOP          SAFETY_RESET
CAL_JOG              CAL_JOG_END          CAL_SAVED
AUDIO                AUDIO_ADDED          AUDIO_REMOVED
AUDIO_MAPPED         AUDIO_TEST
VISION               HUMAN_DETECTED       HUMAN_LOST
OBJECT_DETECTED
```

`COMMAND_REJECTED` means validation or the safety layer refused it.
`COMMAND_CANCELLED` means a pending command was dropped. Neither is a joke —
keeping them distinct from the comedic `IGNORED` verdict is what lets the log
tell "deliberately unhelpful" apart from "actually broken".

### 2.5 `command`

The feedback for one button press. Sent up to twice: once on arrival if the
bin is sitting on it, and once when it resolves.

```json
{
  "type": "command", "kind": "drive",
  "requested": "FORWARD", "actual": "BACKWARD",
  "verdict": "MODIFIED", "delayMs": 1700,
  "speedReq": 60, "speedAct": 17,
  "reason": "Because I can.", "quip": "I optimized it.",
  "phase": "done", "simulated": false
}
```

| Field | Values |
|---|---|
| `kind` | `drive` or `action` |
| `verdict` | `OBEYED`, `MODIFIED`, `IGNORED`, `REJECTED` |
| `phase` | `received` (delay started), `executing`, `done` |
| `reason` | The WHY panel's text. Empty when it simply obeyed. |
| `simulated` | The target hardware is not fitted, so nothing physical happened. |

A `received` phase with a non-zero `delayMs` is the bin telling you it has
heard you and is choosing not to act yet. If the control is released before
the delay expires, the command is dropped and a final `done` arrives with
`reason: "You let go."`

### 2.6 `sound`

```json
{ "type": "sound", "seq": 12, "event": "human_detected",
  "label": "Human detected", "clip": "hi_chellam_i_love_u.wav" }
```

"Play this." The bin sends no audio, ever: the browser already holds the
clip (fetched from `/audio/<clip>` and decoded) and plays it. `seq` is
shared with the BLE and USB copies of the same message (§4, §5) so a phone
on two links plays once. Only sent when a clip is assigned to the event and
the event's cooldown allows it (1.5 s per event, 250 ms between any two;
`estop` bypasses both).

### 2.7 `audio_changed`

```json
{ "type": "audio_changed" }
```

The clip library or the map changed (an upload, a delete, an assignment,
from any phone). Refetch `GET /api/audio`.

---

## 3. HTTP

| Route | Method | Purpose |
|---|---|---|
| `/` | GET | The dashboard from LittleFS, or the built-in fallback page. |
| `/ws` | GET | WebSocket upgrade. |
| `/audio/<name>` | GET | A clip, `Cache-Control: max-age=86400`. The browser appends `?v=<size>` so a replaced clip is refetched. |
| `/api/audio` | GET | The library: `{"clips":[{"name","size"}],"map":{event:clip},"events":[{"n","id","label","desc"}],"fs":{"used","total"},"maxClip"}`. `map` has every event key; `""` means unassigned. |
| `/api/audio` | POST | Multipart upload of one clip. The filename is sanitised (lower-case, `[a-z0-9._-]`, spaces to `_`, audio extension required, ≤ 39 chars, ≤ 512 KB). 400 with a reason on refusal. |
| `/api/audio?name=x` | DELETE | Remove a clip. Any event using it becomes unassigned. |
| `/api/audio/map` | POST | Form `event=<id>&clip=<name>`; empty `clip` unassigns. 404 if the clip does not exist. Saved to `/audio/map.json`. |
| `/api/vision` | POST | Form `persons`, `objects`, `conf`, `src` — the same report as §1.8, for a camera board that would rather not open a WebSocket. |
| `/api/wifi` | POST | Form-encoded `ssid` and `pass`. Stored in NVS; the board restarts. |

`/api/wifi` is reachable over the AP fallback, which is the only way to
configure a board that has never been on a network. It is not
authenticated beyond the AP's own WPA2 password — the same trust boundary as
the motor controls it sits next to. The audio routes share that boundary:
anyone who can drive the bin can change what it says.

---

## 4. Bluetooth Low Energy

Device name `TRASHBOT`, advertising the service UUID. One service, two
characteristics; the UUIDs are also in the `hello` message.

| Characteristic | UUID | Properties | Payload |
|---|---|---|---|
| sound | `7a5b0002-…` | READ, NOTIFY | `seq;eventNumber;clip` e.g. `12;3;hi_chellam_i_love_u.wav` |
| command | `7a5b0003-…` | WRITE, WRITE_NR | Any §1 message, as JSON, ≤ 512 bytes |

The sound payload is not JSON because a phone that never negotiated a
larger MTU sees only the first 20 bytes. `seq;eventNumber` always fits;
`eventNumber` is `n` from `/api/audio`'s event list, and the browser looks
the clip up in the map it already holds if the name was cut off. The bin
requests an MTU of 247.

Writes go through the same validate-and-queue path as WebSocket frames. A
connected phone counts as a client for the `NO CLIENT` rule and its
silence trips the 1500 ms link timeout like anyone else's, so a phone that
is driving over Bluetooth must also ping over Bluetooth. Up to 3 connections.

---

## 5. USB serial

115200 baud, the same port as the boot log. One line per sound, prefixed so
a reader can skip everything else:

```
SND {"type":"sound","seq":12,"event":"human_detected","clip":"hi_chellam_i_love_u.wav"}
```

Any inbound line that starts with `{` is handed to the same validator as
the WebSocket, so a laptop on Web Serial or a phone on WebUSB can drive the
bin and hear it with no radio at all. A serial peer cannot be detected, so
one counts as a client only while it has sent a JSON line inside the
1500 ms link timeout — keep pinging, as over any other link.

---

## 6. UART2 (camera board)

`PIN_VISION_RX` GPIO 16, `PIN_VISION_TX` GPIO 17, 115200 8N1, 3.3 V. One
report per line, keys in any order, unknown keys ignored, lines not
starting with `VISION` dropped (a camera board's own debug output is fine
on the same wire):

```
VISION persons=1 objects=cup,bottle conf=83
```

---

## 7. Adding a command

1. Add the value to the relevant enum in `src/core/types.h`, at the end.
   Do not renumber existing values.
2. Add its wire spelling to the matching `parse*()` in `src/net/webLayer.cpp`,
   and to `dirName()` / `actionName()` in `types.h` if it needs a display name.
3. Add a case to `Pipeline::handle()`.
4. Decide whether the personality engine may transform it. If it can stop a
   motor or is labelled as doing nothing, it must bypass the engine — see
   `ACT_DO_NOTHING` and `DIR_STOP` for the two existing precedents.
5. Add the button to `data/index.html` and its handler to `data/app.js`.
6. Update §1 or §2 of this document.

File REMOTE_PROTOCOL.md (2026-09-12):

# REMOTE PROTOCOL

ESP-NOW link between **BIN CONTROL SYSTEM v0.0001** and **USELESS TRASH BIN**.

Chosen over Wi-Fi/MQTT because it is peer-to-peer, needs no router, no
credentials and no association, and delivers a keypress in single-digit
milliseconds. At a hackathon the venue Wi-Fi is congested, captive-portalled,
or both. ESP-NOW does not care.

Reference: <https://developer.espressif.com/blog/2024/08/arduino-esp-now-lib/>

---

## 1. Link parameters

| | |
|---|---|
| Transport | ESP-NOW (802.11 vendor action frames) |
| Channel | 1 (`BINCHAD_ESPNOW_CHANNEL`) — **both ends pin it explicitly** |
| Encryption | None |
| Mode | `WIFI_STA`, disconnected |
| Pairing | None. The remote broadcasts; the bin answers and both then remember each other as unicast peers. |
| Device ID | `0x2A` (`BINCHAD_DEVICE_ID`) — change it to run two bins in one room |
| Latency | ~2–5 ms typical, well inside the 200 ms target |
| Range | 30 m+ line of sight; more than enough for a stage |

Both firmwares call `esp_wifi_set_channel()` at startup. Without that, the two
boards can settle on different channels and the link silently does nothing —
the single most common ESP-NOW failure.

### The shared header

`protocol.h` exists **twice, byte-identical**:

```
firmware/BinChad/src/remote/protocol.h
firmware/BinRemote/src/config/protocol.h
```

Arduino sketches cannot share files outside their own folder, so it is
duplicated rather than symlinked. **If you edit one, copy it over the other.**
A mismatch fails the checksum on every packet, and you will spend an hour
blaming the antenna.

---

## 2. Packet formats

### 2.1 Remote → Bin (`PKT_COMMAND`, 8 bytes)

```c
struct __attribute__((packed)) RemotePacket {
    uint8_t deviceId;   // 0x2A
    uint8_t version;    // 1
    uint8_t type;       // PKT_COMMAND = 0x01
    uint8_t command;    // RemoteCommand
    uint8_t sequence;   // ++ per keypress, wraps at 255
    uint8_t repeat;     // 0 = first send, 1..2 = retransmit of the same sequence
    uint8_t flags;      // bit0 held, bit1 low battery
    uint8_t checksum;
};
```

| Offset | Field | Notes |
|---:|---|---|
| 0 | `deviceId` | Rejected if it is not `0x2A`. |
| 1 | `version` | Rejected on mismatch — no negotiation, this is a hackathon. |
| 2 | `type` | Bin accepts `PKT_COMMAND` only. |
| 3 | `command` | See §3. |
| 4 | `sequence` | The de-duplication key. |
| 5 | `repeat` | Informational; the bin de-duplicates by `sequence`, not by this. |
| 6 | `flags` | `PKT_FLAG_HELD`, `PKT_FLAG_LOWBATT`. |
| 7 | `checksum` | See §2.3. |

### 2.2 Bin → Remote (`PKT_ACK`, 8 bytes)

```c
struct __attribute__((packed)) BinStatusPacket {
    uint8_t deviceId;
    uint8_t version;
    uint8_t type;        // PKT_ACK = 0x02
    uint8_t ackSequence; // the sequence being answered, 0xFF if unsolicited
    uint8_t stateId;     // PersonalityState
    uint8_t obeyed;      // 1 = the bin actually did what was asked (rare)
    uint8_t frustration; // 0..12
    uint8_t checksum;
};
```

The remote uses `obeyed` and `frustration` to drive its **COMPLIANCE %**
readout, which only ever goes down.

### 2.3 Checksum

```c
static inline uint8_t binchad_checksum(const uint8_t *b, uint8_t len) {
    uint8_t x = 0;
    for (uint8_t i = 0; i < len - 1; ++i) x ^= b[i];
    return (uint8_t)(~x);          // inverted on purpose
}
```

XOR of every byte except the last, **then inverted**. The inversion matters:
an all-zero buffer — the classic symptom of a dead link or a truncated read —
produces checksum `0xFF`, not `0x00`, so it fails validation instead of
looking like a valid `CMD_NONE`.

---

## 3. Command set

| Value | Name | What the remote means | What the bin tends to do |
|---:|---|---|---|
| 0x00 | `CMD_NONE` | — | The silent treatment (a valid outcome of mistranslation) |
| 0x01 | `CMD_UP` | eye up | usually down |
| 0x02 | `CMD_DOWN` | eye down | usually up |
| 0x03 | `CMD_LEFT` | eye left | usually right |
| 0x04 | `CMD_RIGHT` | eye right | usually left |
| 0x05 | `CMD_OK` | confirm | `OK / IS SUBJECTIVE` |
| 0x06 | `CMD_OPEN` | open the lid | closes it |
| 0x07 | `CMD_CLOSE` | close the lid | opens it |
| 0x08 | `CMD_STOP` | stop everything | everything gets faster for one second |
| 0x09 | `CMD_AI` | engage AI | 12 s of theatre, then something unrelated |
| 0x0A | `CMD_ANGRY` | be angry | is angry (this one works) |
| 0x0B | `CMD_MOOD` | change mood | picks a random personality state |
| 0x0C | `CMD_NORMAL` | normal mode | `USE THE BUTTON.` and looks at it |
| 0x0D | `CMD_MUTE` | mute | volume to maximum |
| 0x0E | `CMD_LIGHT` | lights on | lights off |
| 0x0F | `CMD_DARK` | lights off | full brightness white |
| 0x10 | `CMD_SECRET` | (BOOT button) | `YOU FOUND / NOTHING.` |
| 0x1F | `CMD_PING` | keepalive | nothing — no behaviour attached |

`CMD_PING` is sent every 1.5 s so the bin's `REMOTE LOST / Good.` message
appears only when the remote is genuinely gone, not merely idle.

---

## 4. Reliability

**Retransmission.** Each keypress is transmitted **3 times, 40 ms apart**,
with the same `sequence` and an incrementing `repeat`. ESP-NOW is unicast and
already ACKed at the MAC layer, but a remote pressed at the moment the bin's
Wi-Fi task is busy can still drop a frame.

**De-duplication.** The bin accepts a `(sequence, command)` pair once per
`REMOTE_REPEAT_MS` (250 ms). The three copies of one press therefore produce
exactly one reaction.

**Ring buffer.** The receive callback runs in Wi-Fi task context, so it does
the minimum possible: validate, push into an 8-entry ring, return. All
interpretation happens in `poll()` on the main loop. Nothing is allocated and
nothing blocks inside the callback.

**Timeout.** No valid packet for `REMOTE_TIMEOUT_MS` (4 s) sets
`remoteConnected = false`. The bin keeps working; it just becomes smug about
it. Reconnection is automatic and produces `REMOTE FOUND / Unfortunately.`

**Broadcast fallback.** Until a peer is learned, both ends send to
`FF:FF:FF:FF:FF:FF`. You never have to write down a MAC address, which means
you cannot lose the piece of paper it was written on.

---

## 5. The mistranslation engine

This is the part that makes the joke land, and the part most likely to be
mistaken for a bug. It lives in `Personality::mistranslate()`, on the **bin**,
not on the remote.

> **Why the bin and not the remote:** the remote is a truthful transmitter
> attached to a dishonest *display*. Keeping the misbehaviour in one place —
> and keeping the wire protocol honest — means you can trust the serial log
> while debugging. `[remote] asked OPEN -> doing CLOSE` tells you the link is
> perfect and the bin is simply being difficult.

### 5.1 Base weights

Per the design brief:

| Outcome | Weight | Result |
|---|---:|---|
| Correct | 10 | Does what you asked. `obeyed = true`. Followed by `...FINE.` |
| Opposite | 40 | `oppositeOf()`: UP↔DOWN, LEFT↔RIGHT, OPEN↔CLOSE, LIGHT↔DARK |
| Wrong direction | 25 | A different direction, never the requested one |
| Random action | 20 | Anything from `kAnything[]` |
| Nothing | 5 | `CMD_NONE` — refusal line, red flash |

### 5.2 Escalation

`frustration` increments on every remote command (capped at 12) and decays by
1 every 12 s, so putting the remote down for a couple of minutes resets the
demo.

```
wCorrect  = (frustration >= 6) ? 0 : (10 - frustration)
wOpposite = 40 + frustration * 2
wWrongDir = 25
wRandom   = 20 + frustration
wNothing  = 5
```

After six presses the probability of compliance is **exactly zero** and stays
there. In `P_ANGRY` the table is replaced entirely with
`correct 0 / opposite 30 / wrongDir 25 / random 45 / nothing 15`.

| Presses (= frustration) | P(correct) | P(opposite) | P(wrong dir) | P(random) | P(nothing) |
|---:|---:|---:|---:|---:|---:|
| 1 | 8.8 % | 41.2 % | 24.5 % | 20.6 % | 4.9 % |
| 3 | 6.6 % | 43.4 % | 23.6 % | 21.7 % | 4.7 % |
| 6 | **0 %** | 48.1 % | 23.1 % | 24.1 % | 4.6 % |
| 12 (cap) | **0 %** | 50.8 % | 19.8 % | 25.4 % | 4.0 % |
| *in `P_ANGRY`* | **0 %** | 26.1 % | 21.7 % | 39.1 % | 13.0 % |

(Weights are normalised over their running total, so the percentages shift as
the table grows — which is why "opposite 40" does not mean 40 %.)

### 5.3 Commands that bypass the engine

`CMD_AI`, `CMD_STOP`, `CMD_MUTE`, `CMD_MOOD`, `CMD_ANGRY`, `CMD_NORMAL` and
`CMD_SECRET` pass through untouched — their joke is implemented downstream in
`executeCommand()` rather than by substitution. Mistranslating "STOP" into
"LEFT" would be less funny than STOP making everything faster.

### 5.4 Determinism

The engine draws from the seeded xorshift32 in `Personality`, not `rand()`.
Same seed plus same sequence of presses gives the same sequence of wrong
answers. This is what makes the behaviour read as *deliberate* rather than
*broken*, and it means you can rehearse the demo and reproduce a bug.

---

## 6. Adding a command

1. Add the value to `RemoteCommand` in `protocol.h`. **Never renumber existing
   values** — the two firmwares are flashed independently and will disagree.
2. Add a case to `binchad_cmd_name()`.
3. Copy `protocol.h` to the other firmware.
4. Bin side: add a case to `BehaviorManager::executeCommand()`.
5. Decide whether it should bypass the mistranslation engine (§5.3).
6. Remote side: add it to `kButtons[]`, or to `kLadderCommands[]` plus a new
   resistor in the ladder.
7. Update the table in §3 of this document.

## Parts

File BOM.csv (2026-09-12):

Category | Item | Qty | Preferred specification | Purpose | Alternative | Unit price USD | Line total USD | Where to look | Notes
Control | ESP32-S3 dev board | 1 | ESP32-S3-DevKitC-1, USB-C, N8R2 or N16R8 | Main controller | ESP32-S3-WROOM DevKit clone; ESP32-WROOM-32 (lose native USB) | 9.00 | 9.00 | https://www.google.com/search?q=ESP32-S3-DevKitC-1+N16R8 | N8R2 frees GPIO33-37. N16R8 has more PSRAM if you add a camera later.
Control | ESP32-C3 dev board | 1 | ESP32-C3 SuperMini, USB-C | Remote controller | ESP32-C3-DevKitM-1; any ESP32 board with 13 free GPIO | 4.00 | 4.00 | https://www.google.com/search?q=ESP32-C3+SuperMini | Pin map in PINOUT.md assumes the SuperMini pinout.
Actuator | High-torque servo | 1 | MG996R, metal gear, 9.4 kgf.cm @ 5V | Lid | DS3218 (20 kgf.cm) for a heavier lid; DS3225 | 5.50 | 5.50 | https://www.google.com/search?q=MG996R+servo | See the torque budget in CAD_README.md before substituting. Do not fit an SG90.
Actuator | Micro servo metal gear | 2 | MG90S, 2.2 kgf.cm | Eye pan and tilt | SG90 (plastic gear, shorter life) | 3.00 | 6.00 | https://www.google.com/search?q=MG90S+servo | Metal gear matters here - the eye moves constantly.
Actuator | Micro servo | 2 | SG90, 1.8 kgf.cm | Finger and hatch | MG90S for longer life | 2.00 | 4.00 | https://www.google.com/search?q=SG90+servo | The finger only has to flip a switch. Low torque is fine and safer.
Sensor | Time-of-flight sensor | 2 | VL53L0X breakout, I2C, XSHUT broken out | Throat detection and person detection | VL53L1X (longer range); HC-SR04 (cheaper, worse) | 4.50 | 9.00 | https://www.google.com/search?q=VL53L0X+breakout+XSHUT | XSHUT pin is REQUIRED - two sensors share address 0x29 at boot.
Sensor | IR break-beam pair | 1 | 3-pin IR obstacle module or a beam-break pair, 3.3V capable | Lid safety backup | Second VL53L0X; omit (set USE_IR_THROAT 0) | 2.50 | 2.50 | https://www.google.com/search?q=IR+break+beam+sensor+3.3V | Second independent channel for the hand-detect safety path.
Sensor | Microswitch SPDT | 2 | Lever microswitch, 5A, with roller or lever | Lid open and closed limits | Hall sensor + magnet (no contact wear) | 0.60 | 1.20 | https://www.google.com/search?q=SPDT+lever+microswitch | Wire COM-GND and NC-GPIO so a broken wire fails safe.
UI | OLED display | 2 | 0.96in SSD1306 128x64 I2C | Bin face and remote status | 1.3in SH1106 (change the driver); ST7789 TFT | 3.50 | 7.00 | https://www.google.com/search?q=0.96+SSD1306+OLED+I2C | One for the bin, one for the remote. Check the address (0x3C or 0x3D).
UI | WS2812B LED strip | 1 | 12 pixels, 5V, 60/m cut to length | Lighting and mood | WS2812B ring 12; any addressable 5V strip | 3.00 | 3.00 | https://www.google.com/search?q=WS2812B+strip+5V | 12 pixels at brightness 90 draws about 220 mA.
Audio | I2S amplifier | 1 | MAX98357A breakout, 3.2W mono | Audio | DFPlayer Mini + microSD (set AUDIO_BACKEND) | 4.50 | 4.50 | https://www.google.com/search?q=MAX98357A+I2S+amplifier | I2S build streams WAV from LittleFS - no SD card needed.
Audio | Speaker | 1 | 4 ohm 3W, 40-50 mm | Audio | 8 ohm 2W (quieter) | 2.50 | 2.50 | https://www.google.com/search?q=4+ohm+3W+speaker+40mm | Never ground either terminal - the amp output is bridge-tied.
Control input | Latching pushbutton | 1 | 19 mm illuminated latching, 1NO1NC + LED | NORMAL MODE switch | 12 mm toggle switch; any latching switch the finger can reach | 4.00 | 4.00 | https://www.google.com/search?q=19mm+illuminated+latching+pushbutton | Must LATCH - a momentary button gives the finger nothing to turn off.
Control input | Arcade button 16 mm | 7 | 16 mm momentary, screw mount | Remote D-pad OPEN CLOSE | 12 mm tactile with printed caps | 0.90 | 6.30 | https://www.google.com/search?q=16mm+arcade+button+momentary
Control input | Tactile switch 12 mm | 8 | 12x12 mm tactile with cap | Remote aux ladder | 6 mm tactile | 0.25 | 2.00 | https://www.google.com/search?q=12mm+tactile+switch+cap
Control input | Micro tactile switch | 1 | 6 mm tactile | Hidden demo trigger | Reed switch + magnet (fully concealed) | 0.20 | 0.20 | https://www.google.com/search?q=6mm+tactile+switch | Mount where the operator's hand naturally rests. See HACKATHON_DEMO.md.
Power | PSU 5V 5A | 1 | 5V 5A 25W, barrel jack or screw terminal, CE/UL marked | Main supply | 5V 4A (tighter); 12V 5A + buck to 5V | 11.00 | 11.00 | https://www.google.com/search?q=5V+5A+power+supply+25W | Buy a marked supply from a real vendor. This one plugs into the wall.
Power | Buck converter | 1 | LM2596 or MP1584, 3A, adjustable | Logic rail if you feed 12V | Not needed on a 5V-only build | 1.50 | 1.50 | https://www.google.com/search?q=LM2596+buck+converter | Only required if your main supply is 12V.
Power | Master switch | 1 | DPST rocker, 10A, panel mount | Cuts actuator power | SPST 10A rocker | 1.50 | 1.50 | https://www.google.com/search?q=DPST+rocker+switch+10A | Must break the servo rail, not the logic rail.
Power | Fuse holder + fuse | 1 | Panel blade fuse holder + 5A blade fuse | Overcurrent protection | Polyfuse 4A hold | 1.20 | 1.20 | https://www.google.com/search?q=panel+mount+blade+fuse+holder
Power | P-channel MOSFET | 1 | IRF4905 or AO3401 (low current), TO-220 or SOT-23 | Servo rail soft cutoff | Automotive relay 5V 10A | 0.80 | 0.80 | https://www.google.com/search?q=IRF4905+P+channel+MOSFET | With a 2N7002 N-FET as the level shifter. Circuit in WIRING.md.
Power | N-channel MOSFET small signal | 2 | 2N7000 or 2N7002 | P-FET gate driver and lamp driver | BS170 | 0.20 | 0.40 | https://www.google.com/search?q=2N7000+MOSFET
Power | Electrolytic capacitor | 1 | 1000 uF 10V low-ESR | Servo rail bulk | 2x 470 uF in parallel | 0.50 | 0.50 | https://www.google.com/search?q=1000uF+10V+low+ESR+capacitor | The single most important part for avoiding brownout resets.
Power | Electrolytic capacitor | 2 | 470 uF 10V | LED rail and audio rail | 220 uF | 0.30 | 0.60 | https://www.google.com/search?q=470uF+10V+capacitor
Power | Ceramic capacitor | 10 | 100 nF 50V | Local decoupling | - | 0.05 | 0.50 | https://www.google.com/search?q=100nF+ceramic+capacitor
Passive | Resistor kit | 1 | 1/4W assortment incl. 330R 1k 2.2k 4.7k 10k 22k 47k 100k | LED data and remote ladder | Individual values | 3.00 | 3.00 | https://www.google.com/search?q=1/4W+resistor+assortment+kit | The remote ladder needs one each of 1k 2.2k 4.7k 10k 22k 47k 100k.
Interconnect | Terminal blocks | 4 | 5.08 mm screw terminal, 2-3 way, PCB mount | Power distribution | WAGO 221 lever nuts | 0.50 | 2.00 | https://www.google.com/search?q=5.08mm+PCB+screw+terminal
Interconnect | JST-XH connector kit | 1 | 2/3/4-pin with crimps and shells | Module connections | Dupont with locking shells | 8.00 | 8.00 | https://www.google.com/search?q=JST+XH+connector+kit+crimp | Locking shells - vibration walks bare Dupont off headers.
Interconnect | Silicone hookup wire | 1 | 22 AWG and 18 AWG, assorted colours | Wiring | PVC hookup wire | 9.00 | 9.00 | https://www.google.com/search?q=silicone+hookup+wire+22AWG+kit | 18-20 AWG for the servo rail, 22-26 AWG for signals.
Interconnect | Heat-shrink assortment | 1 | 2:1, 1.5-10 mm | Insulation | Electrical tape (worse) | 4.00 | 4.00 | https://www.google.com/search?q=heat+shrink+tubing+assortment
Interconnect | Perfboard | 1 | 70x90 mm double-sided | Power distribution and breakout | Custom PCB; solderable breadboard | 1.50 | 1.50 | https://www.google.com/search?q=70x90+perfboard+double+sided
Mechanical | Heat-set inserts M3 | 50 | M3 x 5.0 mm brass, knurled | Serviceable joints | M3 nuts in captive pockets | 0.12 | 6.00 | https://www.google.com/search?q=M3+heat+set+insert+5mm+brass | Needs a soldering iron with an insert tip - about 10 dollars extra.
Mechanical | Socket cap screws M3 | 1 | Assortment M3 x 6/8/10/12/16 mm | Assembly | Any M3 screws | 8.00 | 8.00 | https://www.google.com/search?q=M3+socket+cap+screw+assortment
Mechanical | Steel rod 4 mm | 1 | 4 mm x 200 mm ground rod, or a cut M4 screw | Hinge pin | M4 bolt with the thread turned down | 1.50 | 1.50 | https://www.google.com/search?q=4mm+steel+rod+200mm
Mechanical | Shoulder screws M3 | 2 | M3 x 8 mm shoulder, 4 mm shoulder dia | Linkage pivots | M3 screw + washer + nyloc | 0.80 | 1.60 | https://www.google.com/search?q=M3+shoulder+screw+8mm | A shoulder screw gives a proper bearing surface for the linkage.
Filament | PETG filament | 1 | 1 kg, structural parts | Body brackets tray finger | ABS/ASA if you have an enclosure | 22.00 | 22.00 | https://www.google.com/search?q=PETG+filament+1kg | PETG for anything that carries load or sees heat.
Filament | PLA filament | 1 | 1 kg, cosmetic parts | Panels lid skin remote shell | PETG throughout | 18.00 | 18.00 | https://www.google.com/search?q=PLA+filament+1kg | Cheaper and crisper for cosmetic surfaces.
Filament | TPU filament | 1 | 0.5 kg, 95A | Feet bumpers finger tip | Rubber feet bought in | 14.00 | 14.00 | https://www.google.com/search?q=TPU+95A+filament+500g | The soft finger tip and the lid stop pads come from here.
Optional | Camera module | 1 | OV2640 for ESP32-S3, 24-pin | Optional face and object tracking | Omit - the project must work without it | 6.00 | 0.00 | https://www.google.com/search?q=OV2640+ESP32-S3+camera | NOT in the base build. See README section on optional features.
Optional | Acrylic dome 26 mm | 1 | Clear half-dome or watch glass | Eye lens | Print eye_lens in clear PETG | 1.50 | 0.00 | https://www.google.com/search?q=26mm+clear+acrylic+dome | Printed lens works; a real dome looks better.
Optional | Li-ion cell + holder | 1 | 18650 2000 mAh + holder, or a small USB power bank | Remote power | USB power bank in the battery bay | 6.00 | 0.00 | https://www.google.com/search?q=18650+holder+battery | A power bank is simpler and has no charging circuit to get wrong.

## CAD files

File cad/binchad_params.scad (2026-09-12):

// =============================================================================
//  binchad_params.scad - shared parameters for every printed part.
//
//  Change a number here and every part that references it follows. This is
//  the whole reason the CAD is parametric: the lid width appears in the
//  hinge, the servo mount, the linkage length and the body cut-out, and
//  they must not disagree.
//
//  Units: millimetres. Printer assumptions: 0.4 mm nozzle, 0.2 mm layers.
// =============================================================================

// ---------------------------------------------------------------------------
// PRINT TOLERANCES
// Measured on a stock Ender-style printer. If your holes come out tight,
// raise fit_loose; if pins rattle, lower it. Do not scale whole parts.
// ---------------------------------------------------------------------------
fit_snug   = 0.15;   // press fit, e.g. a pin in a bracket
fit_loose  = 0.35;   // free rotation, e.g. hinge pin in its bore
fit_clear  = 0.60;   // panel in a slot, cable through a hole

$fn = 48;            // curve resolution; drop to 24 while iterating

// ---------------------------------------------------------------------------
// FASTENERS - M3 throughout, heat-set inserts everywhere a screw goes into
// plastic more than once.
// ---------------------------------------------------------------------------
m3_clear    = 3.4;    // through-hole for an M3 screw
m3_tap      = 2.9;    // self-tapping into plastic (single assembly only)
m3_head_d   = 6.2;    // socket-cap head diameter
m3_head_h   = 3.2;
m3_nut_af   = 5.6;    // across flats
m3_nut_h    = 2.6;

// Heat-set insert, M3 x 5.0 mm brass (the common "M3 short" size).
// Bore is deliberately UNDERSIZE - the insert melts its own interference.
insert_m3_d = 4.0;
insert_m3_h = 5.5;

// ---------------------------------------------------------------------------
// BIN BODY
// The reference build wraps a 210 mm square opening. If you are retrofitting
// a bought bin, measure YOUR opening and set these three numbers first.
// ---------------------------------------------------------------------------
bin_opening_x   = 210;
bin_opening_y   = 210;
bin_wall        = 3.0;    // wall thickness of the printed collar
bin_collar_h    = 26;     // how far the printed collar drops over the bin

// ---------------------------------------------------------------------------
// LID
//
//  TORQUE BUDGET - the sum that picks the servo. Redo it if you change
//  anything here; do not assume the reference servo still fits.
//
//     lid_mass_g        180 g   (printed lid + hinge hardware, weighed)
//     lid_cog_mm        110 mm  (hinge axis to centre of gravity)
//     tau_static = m*g*d = 0.180 * 9.81 * 0.110 = 0.194 N.m = 1.98 kgf.cm
//     required   = tau_static * safety_factor(2.0) = 3.96 kgf.cm
//     fitted     = MG996R at 5 V = 9.4 kgf.cm  ->  4.7x margin
//
//  The margin is generous on purpose: it covers a sticky hinge, a cold
//  servo, a sagging 5 V rail and someone resting a hand on the lid.
// ---------------------------------------------------------------------------
lid_x           = 214;
lid_y           = 214;
lid_t           = 3.0;    // top skin
lid_rib_h       = 8;      // stiffening ribs, keeps the lid light AND flat
lid_rib_t       = 2.4;
lid_mass_g      = 180;    // WEIGH YOUR LID and put the real number here
lid_cog_mm      = 110;
lid_safety_factor = 2.0;

lid_open_deg    = 84;     // mechanical travel; firmware uses 12..96 servo deg

// ---------------------------------------------------------------------------
// HINGE
// Two brackets, one 4 mm steel pin (a cut-down M4 screw or 4 mm rod).
// ---------------------------------------------------------------------------
hinge_pin_d     = 4.0;
hinge_boss_d    = 11;
hinge_bracket_t = 6;
hinge_span      = 150;    // centre-to-centre of the two brackets
hinge_offset_z  = 14;     // pin height above the collar top face

// ---------------------------------------------------------------------------
// SERVOS
// ---------------------------------------------------------------------------
// MG996R / DS3218 standard-size body
servo_std_x     = 40.5;
servo_std_y     = 20.0;
servo_std_z     = 38.0;
servo_std_tab_x = 54.0;   // across the mounting tabs
servo_std_tab_t = 2.6;
servo_std_hole_d= 4.2;    // tab holes, M4 or M3 with a washer
servo_std_shaft_off = 10.0; // tab face to output shaft centre

// SG90 / MG90S micro body
servo_micro_x     = 22.8;
servo_micro_y     = 12.4;
servo_micro_z     = 22.5;
servo_micro_tab_x = 32.2;
servo_micro_tab_t = 2.5;
servo_micro_hole_d= 2.3;  // M2 self-tapping
servo_micro_shaft_off = 5.9;

horn_screw_d    = 2.0;    // servo horn retaining screw

// ---------------------------------------------------------------------------
// LINKAGE
// Servo horn -> lid. A two-bar linkage, not a direct horn mount, so the
// servo sits low in the body and the lid gets a better lever arm.
// ---------------------------------------------------------------------------
link_len        = 62;     // hole centre to hole centre - TUNE ON ASSEMBLY
link_w          = 9;
link_t          = 4;
link_hole_d     = 3.2;    // rides on M3 shoulder screws
horn_arm_len    = 25;     // effective servo horn radius

// ---------------------------------------------------------------------------
// USELESS FINGER MODULE
// ---------------------------------------------------------------------------
finger_box_x    = 62;
finger_box_y    = 46;
finger_box_z    = 52;
finger_len      = 58;     // comically long on purpose
finger_w        = 14;
finger_t        = 6;
finger_tip_r    = 5;      // ROUNDED. No sharp edges anywhere near a user.
door_x          = 34;
door_y          = 22;
door_t          = 2.4;

// ---------------------------------------------------------------------------
// NORMAL MODE SWITCH
// A 19 mm latching pushbutton, or a 12 mm toggle. Set to match yours.
// ---------------------------------------------------------------------------
button_hole_d   = 19.2;   // 19 mm latching switch + clearance
button_plate_x  = 56;
button_plate_y  = 56;
button_plate_t  = 4;

// ---------------------------------------------------------------------------
// EYE
// ---------------------------------------------------------------------------
eye_ball_d      = 42;
eye_lens_d      = 26;     // acrylic dome or a printed clear disc
eye_pan_range   = 110;    // degrees, matches EYE_PAN_MIN..MAX in firmware

// ---------------------------------------------------------------------------
// SENSORS
// ---------------------------------------------------------------------------
vl53_pcb_x      = 25.4;   // Adafruit VL53L0X breakout
vl53_pcb_y      = 17.8;
vl53_hole_span  = 20.3;
vl53_hole_d     = 2.6;

oled_pcb_x      = 27.3;   // common 0.96" SSD1306 module
oled_pcb_y      = 27.8;
oled_win_x      = 22.0;
oled_win_y      = 11.5;
oled_hole_span_x= 23.5;
oled_hole_span_y= 23.8;

// ---------------------------------------------------------------------------
// ELECTRONICS TRAY
// ---------------------------------------------------------------------------
tray_x          = 150;
tray_y          = 110;
tray_z          = 4;
tray_wall       = 2.4;
tray_rail_w     = 6;      // slides out on rails; nothing is glued in

// ---------------------------------------------------------------------------
// REMOTE
// ---------------------------------------------------------------------------
remote_x        = 190;    // deliberately, absurdly oversized
remote_y        = 110;
remote_z        = 34;
remote_wall     = 2.4;
remote_btn_d    = 16;     // arcade-style 16 mm buttons
remote_antenna_d= 8;
remote_antenna_h= 120;    // does nothing. Essential.

// ---------------------------------------------------------------------------
// Shared helper modules
// ---------------------------------------------------------------------------

// Rounded box, used everywhere. Centred in X/Y, sitting on Z=0.
module rbox(x, y, z, r = 3) {
    hull() for (dx = [-1, 1], dy = [-1, 1])
        translate([dx * (x/2 - r), dy * (y/2 - r), 0])
            cylinder(r = r, h = z);
}

// Screw hole with a counterbore for the head.
module m3_cbore(depth, head_depth = m3_head_h) {
    cylinder(d = m3_clear, h = depth + 0.2, center = false);
    translate([0, 0, depth - head_depth])
        cylinder(d = m3_head_d, h = head_depth + 0.2);
}

// Heat-set insert boss. Print the bore undersize; the brass makes its own.
module insert_boss(h = insert_m3_h + 2, wall = 2.2) {
    difference() {
        cylinder(d = insert_m3_d + wall * 2, h = h);
        translate([0, 0, h - insert_m3_h])
            cylinder(d = insert_m3_d, h = insert_m3_h + 0.1);
    }
}

// A 45-degree chamfer ring, so top edges are not sharp.
module chamfer_ring(d, c = 1.2) {
    difference() {
        cylinder(d = d + 2, h = c);
        cylinder(d1 = d, d2 = d - c * 2, h = c + 0.1);
    }
}

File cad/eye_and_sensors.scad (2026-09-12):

// =============================================================================
//  eye_and_sensors.scad - the eyeball, its gimbal, and the sensor brackets.
//
//    part = "eye_ball"     x1 - hemisphere shell, takes the lens
//    part = "eye_lens"     x1 - print in clear PETG, or use a 26 mm acrylic dome
//    part = "eye_yoke"     x1 - tilt yoke, carries the ball
//    part = "eye_pan_base" x1 - pan servo mount, carries the yoke
//    part = "tof_bracket"  x2 - VL53L0X breakout bracket (throat + approach)
//    part = "oled_bezel"   x1 - SSD1306 frame, snaps into the front panel
//
//  The eye is the highest-value part of the whole build per gram of
//  filament: an audience reads "it is looking at me" long before it reads
//  any of the electronics. Print the ball in a matte colour and the lens
//  glossy - the contrast is what sells it.
// =============================================================================

include <binchad_params.scad>

part = "all";

// ---------------------------------------------------------------------------
module eye_ball() {
    shell = 2.4;
    difference() {
        sphere(d = eye_ball_d);
        // hollow
        sphere(d = eye_ball_d - shell * 2);
        // flatten the back half - printable, and gives the yoke something
        // to grip
        translate([0, 0, -eye_ball_d]) cube(eye_ball_d * 2, center = true);
        // lens aperture, facing +X
        rotate([0, 90, 0])
            translate([0, 0, eye_ball_d/2 - 3])
                cylinder(d = eye_lens_d, h = 6);
        // lens seat lip
        rotate([0, 90, 0])
            translate([0, 0, eye_ball_d/2 - 4.6])
                cylinder(d = eye_lens_d + 3, h = 1.8);
    }
    // trunnions for the tilt axis
    for (dy = [-1, 1])
        translate([0, dy * (eye_ball_d/2 - 1), 0])
            rotate([90, 0, 0])
                cylinder(d = 5 - fit_loose, h = 5, center = true);
}

module eye_lens() {          // clear PETG, 3 perimeters, no infill
    difference() {
        union() {
            cylinder(d = eye_lens_d - fit_snug, h = 2);
            translate([0, 0, 2]) scale([1, 1, 0.45]) sphere(d = eye_lens_d - 2);
        }
        translate([0, 0, -0.1]) cylinder(d = eye_lens_d - 6, h = 1.2);
    }
}

// ---------------------------------------------------------------------------
module eye_yoke() {
    arm_h = eye_ball_d/2 + 6;
    difference() {
        union() {
            rbox(eye_ball_d + 14, 20, 5, 3);
            for (dy = [-1, 1])
                translate([-(eye_ball_d + 14)/2 + 4, dy * (eye_ball_d/2 + 2) - 2.5, 0])
                    cube([eye_ball_d + 6, 5, arm_h]);
        }
        // tilt bearing bores
        for (dy = [-1, 1])
            translate([0, dy * (eye_ball_d/2 + 2), arm_h - 4])
                rotate([90, 0, 0])
                    cylinder(d = 5 + fit_loose, h = 8, center = true);
        // tilt servo horn slot on one arm
        translate([-3, eye_ball_d/2 - 1, arm_h - 4])
            rotate([90, 0, 0]) cylinder(d = 8, h = 3);
        // pan servo shaft
        translate([0, 0, -0.1]) cylinder(d = 5.8, h = 5.2);
        translate([-4, -2.6, 3.4]) cube([20, 5.2, 1.8]);   // horn pocket
    }
}

module eye_pan_base() {
    difference() {
        union() {
            rbox(46, 34, 4, 3);
            // micro servo cradle standing up
            translate([-servo_micro_x/2 - 2, -servo_micro_y/2 - 2, 4])
                cube([servo_micro_x + 4, servo_micro_y + 4, servo_micro_z + 2]);
        }
        translate([-servo_micro_x/2, -servo_micro_y/2, 3.9])
            cube([servo_micro_x, servo_micro_y, servo_micro_z + 3]);
        for (dx = [-1, 1])
            translate([dx * servo_micro_tab_x/2, 0, 4 + servo_micro_z - 5])
                rotate([90, 0, 0])
                    cylinder(d = servo_micro_hole_d, h = 40, center = true);
        for (dx = [-1, 1])
            translate([dx * 19, 0, -0.1]) m3_cbore(4.2);
    }
}

// ---------------------------------------------------------------------------
// ToF BRACKET
// The throat sensor points straight down; the approach sensor points out at
// roughly chest height. Same bracket, mounted on different faces.
// The 4 mm standoff keeps the VL53L0X's cover glass clear of the plastic -
// a bracket that shadows the emitter is the single most common cause of
// "the sensor reads 8190 forever".
// ---------------------------------------------------------------------------
module tof_bracket() {
    difference() {
        union() {
            rbox(vl53_pcb_x + 10, vl53_pcb_y + 10, 3, 3);
            for (dx = [-1, 1])
                translate([dx * vl53_hole_span/2, 0, 3])
                    cylinder(d = 5.5, h = 4);
        }
        // sensor window - generous, do not let the print shadow the emitter
        translate([0, 0, -0.1]) rbox(vl53_pcb_x - 6, vl53_pcb_y - 6, 3.2, 2);
        for (dx = [-1, 1])
            translate([dx * vl53_hole_span/2, 0, 3 - 0.1])
                cylinder(d = vl53_hole_d, h = 4.2);
        for (dy = [-1, 1])
            translate([0, dy * (vl53_pcb_y/2 + 3), -0.1])
                cylinder(d = m3_clear, h = 3.2);
    }
}

// ---------------------------------------------------------------------------
module oled_bezel() {
    difference() {
        rbox(oled_pcb_x + 12, oled_pcb_y + 12, 4, 3);
        // viewing window
        translate([0, 3.5, -0.1]) rbox(oled_win_x + 1, oled_win_y + 1, 4.2, 1);
        // PCB recess from the back
        translate([0, 0, 4 - 2.0])
            rbox(oled_pcb_x + fit_clear, oled_pcb_y + fit_clear, 2.2, 1);
        for (dx = [-1, 1], dy = [-1, 1])
            translate([dx * oled_hole_span_x/2, dy * oled_hole_span_y/2, -0.1])
                cylinder(d = 2.4, h = 4.2);
    }
}

// ---------------------------------------------------------------------------
if (part == "eye_ball")          eye_ball();
else if (part == "eye_lens")     eye_lens();
else if (part == "eye_yoke")     eye_yoke();
else if (part == "eye_pan_base") eye_pan_base();
else if (part == "tof_bracket")  tof_bracket();
else if (part == "oled_bezel")   oled_bezel();
else {
    translate([  0,  0, 0]) eye_ball();
    translate([ 60,  0, 0]) eye_yoke();
    translate([130,  0, 0]) eye_pan_base();
    translate([  0, 70, 0]) tof_bracket();
    translate([ 60, 70, 0]) oled_bezel();
    translate([130, 70, 0]) eye_lens();
}

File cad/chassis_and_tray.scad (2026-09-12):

// =============================================================================
//  chassis_and_tray.scad - electronics tray, button housing, feet, panels.
//
//    part = "tray"          x1 - slide-out electronics tray
//    part = "tray_rails"    x2 - rails that the tray slides on
//    part = "button_plate"  x1 - NORMAL MODE switch mount
//    part = "service_panel" x1 - removable rear access panel
//    part = "foot"          x4 - TPU foot
//    part = "led_diffuser"  x1 - strip diffuser for the WS2812 ring
//    part = "speaker_grille"x1 - speaker cover
//
//  Serviceability rule for this whole project: nothing is glued and nothing
//  is buried. Every module comes out on M3 screws into heat-set inserts, and
//  the tray slides out of the back with the wiring still attached. At a
//  hackathon you will be debugging this on a table with ten minutes to go,
//  and a bin you have to destroy to open is a bin you cannot fix.
// =============================================================================

include <binchad_params.scad>

part = "all";

// ---------------------------------------------------------------------------
module tray() {
    difference() {
        union() {
            rbox(tray_x, tray_y, tray_z, 4);
            // low retaining lip
            difference() {
                rbox(tray_x, tray_y, tray_z + 8, 4);
                translate([0, 0, tray_z])
                    rbox(tray_x - tray_wall*2, tray_y - tray_wall*2, 10, 3);
            }
            // rail tongues
            for (dx = [-1, 1])
                translate([dx * (tray_x/2 + tray_rail_w/2 - 0.5) - tray_rail_w/2, -tray_y/2, 0])
                    cube([tray_rail_w, tray_y, 3]);
            // pull handle
            translate([0, -tray_y/2 - 6, 0]) rbox(40, 14, 6, 3);
        }

        // ESP32-S3 DevKitC-1 mounting pattern (nominal 25.4 x 52.1 hole span)
        for (dx = [-1, 1], dy = [-1, 1])
            translate([dx * 25.4/2 - 40, dy * 52.1/2, -0.1])
                cylinder(d = m3_tap, h = tray_z + 0.2);

        // Generic perfboard / buck / amp mounting grid, 10 mm pitch.
        // Drill what you need; the rest is ventilation.
        for (gx = [-2 : 4], gy = [-4 : 4])
            translate([gx * 15 + 15, gy * 11, -0.1])
                cylinder(d = 3.2, h = tray_z + 0.2);

        // cable pass-throughs
        for (dy = [-1, 1])
            translate([tray_x/2 - 12, dy * 30, -0.1])
                hull() for (dx = [0, 14]) translate([dx - 7, 0, 0])
                    cylinder(d = 10, h = tray_z + 0.2);

        // handle finger slot
        translate([0, -tray_y/2 - 6, 2]) rbox(28, 8, 6, 2);
    }
}

module tray_rails() {
    difference() {
        cube([12, tray_y + 10, 10]);
        // slot the tray tongue rides in
        translate([-0.1, -0.1, 3.5]) cube([tray_rail_w + fit_clear + 0.1, tray_y + 10.2, 3.4]);
        for (dy = [20, tray_y - 10])
            translate([8, dy, -0.1]) cylinder(d = m3_clear, h = 10.2);
    }
}

// ---------------------------------------------------------------------------
// BUTTON PLATE
// The NORMAL MODE switch and, critically, the geometry that puts it within
// reach of the finger. finger_reach below is the number to check on
// assembly: the switch face must sit inside the finger's arc.
// ---------------------------------------------------------------------------
finger_reach = finger_len + 6;    // tip travel from the hatch

module button_plate() {
    difference() {
        union() {
            rbox(button_plate_x, button_plate_y, button_plate_t, 5);
            // raised collar so the switch body is supported square
            cylinder(d = button_hole_d + 8, h = button_plate_t + 2);
        }
        translate([0, 0, -0.1])
            cylinder(d = button_hole_d, h = button_plate_t + 2.2);
        // anti-rotation notch found on most 19 mm latching switches
        translate([button_hole_d/2 - 0.6, -1.6, -0.1])
            cube([2.4, 3.2, button_plate_t + 2.2]);
        for (dx = [-1, 1], dy = [-1, 1])
            translate([dx * (button_plate_x/2 - 6), dy * (button_plate_y/2 - 6), -0.1])
                m3_cbore(button_plate_t + 0.2);
    }
    // Assembly aid: a witness mark showing where the finger tip should land.
    // Printed 0.4 mm proud - sand it off once you are happy with the reach.
    translate([0, 0, button_plate_t + 2])
        difference() {
            cylinder(d = button_hole_d + 6, h = 0.4);
            cylinder(d = button_hole_d + 4, h = 0.5);
        }
}

// ---------------------------------------------------------------------------
module service_panel() {
    difference() {
        rbox(160, 120, 3, 5);
        // ventilation slots - servos and the buck converter both like air
        for (gy = [-3 : 3])
            translate([0, gy * 14, -0.1])
                hull() for (dx = [-1, 1])
                    translate([dx * 55, 0, 0]) cylinder(d = 7, h = 3.2);
        for (dx = [-1, 1], dy = [-1, 1])
            translate([dx * 72, dy * 52, -0.1]) m3_cbore(3.2, 2.0);
        // USB-C service cut-out, so the board can be flashed without opening
        translate([-58, -52, -0.1]) cube([14, 10, 3.2]);
    }
}

// ---------------------------------------------------------------------------
module foot() {              // TPU, 30% infill - it should squash a little
    difference() {
        union() {
            cylinder(d1 = 34, d2 = 28, h = 10);
            translate([0, 0, 10]) cylinder(d = 20, h = 4);
        }
        translate([0, 0, 10 - 0.1]) cylinder(d = insert_m3_d + 0.4, h = 6);
        // concave underside, so it grips rather than skates
        translate([0, 0, -3]) scale([1, 1, 0.35]) sphere(d = 30);
    }
}

// ---------------------------------------------------------------------------
module led_diffuser() {
    len = 180; w = 14;
    difference() {
        union() {
            translate([-len/2, -w/2, 0]) cube([len, w, 3]);
            translate([-len/2, 0, 3]) rotate([0, 90, 0])
                cylinder(d = w, h = len);
        }
        // channel for a 10 mm WS2812 strip
        translate([-len/2 - 0.1, -5.5, -0.1]) cube([len + 0.2, 11, 3.2]);
        translate([-len/2 - 0.1, 0, 3]) rotate([0, 90, 0])
            cylinder(d = w - 2.6, h = len + 0.2);
    }
}

module speaker_grille() {
    difference() {
        cylinder(d = 52, h = 3);
        // ring = [radius, hole count]. Paired deliberately - a nested
        // for(r=..,n=..) in OpenSCAD is a cartesian product, not a zip.
        for (ring = [[8, 6], [16, 12]])
            for (i = [0 : ring[1] - 1])
                rotate([0, 0, i * 360/ring[1]])
                    translate([ring[0], 0, -0.1]) cylinder(d = 4, h = 3.2);
        cylinder(d = 5, h = 3.2);
        for (i = [0 : 3])
            rotate([0, 0, 45 + i * 90])
                translate([23, 0, -0.1]) cylinder(d = 2.6, h = 3.2);
    }
}

// ---------------------------------------------------------------------------
if (part == "tray")               tray();
else if (part == "tray_rails")    tray_rails();
else if (part == "button_plate")  button_plate();
else if (part == "service_panel") service_panel();
else if (part == "foot")          foot();
else if (part == "led_diffuser")  led_diffuser();
else if (part == "speaker_grille")speaker_grille();
else {
    translate([   0,    0, 0]) tray();
    translate([ 180,    0, 0]) tray_rails();
    translate([   0,  150, 0]) button_plate();
    translate([ 100,  150, 0]) foot();
    translate([ 200,  150, 0]) speaker_grille();
    translate([   0, -160, 0]) led_diffuser();
}

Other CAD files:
cad/finger_module.scad
cad/lid_mechanism.scad
cad/remote_enclosure.scad

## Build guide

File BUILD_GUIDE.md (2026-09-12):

# BUILD GUIDE

Assembly and calibration, in the order that works.

**Read §1 before you do anything else.** The single most common way to lose a
weekend on a build like this is to wire everything, flash it once, and then
debug five interacting faults simultaneously.

---

## 1. Build order

Each phase ends with a working, testable thing. Do not start the next phase
until the current one passes.

| Phase | Add | Test that it passes |
|---:|---|---|
| 1 | ESP32-S3 + lid servo on the bench | Servo sweeps 12°→96° smoothly, no buzz when parked |
| 2 | Both lid limit switches | `[hb]` shows the switch states changing as you move the lid by hand |
| 3 | Throat VL53L0X | `thr=` in the heartbeat tracks your hand |
| 4 | OLED | Boot screen, then the animated eye |
| 5 | WS2812B strip | Idle breathe, no flicker |
| 6 | Audio | `boot.wav` plays on reset |
| 7 | Finger cartridge (bench, unmounted) | Full hatch → pause → extend → retract cycle |
| 8 | Remote hardware | All 15 buttons print `[tx]` lines |
| 9 | ESP-NOW | `[remote] asked X -> doing Y` appears on the bin |
| 10 | Mistranslation | OPEN closes. Press it six times; compliance hits zero |
| 11 | Personality | Miss three times; the lines escalate |
| 12 | Integration | Full self-test passes, all subsystems `OK` |
| 13 | Final enclosure | Everything mounted, tray slides out, lid lifts off |

Phases 1–6 are all bench work on a breadboard. Do not mount anything in the
bin until phase 12 passes on the bench.

---

## 2. Before you start

**Tools:** soldering iron with a heat-set-insert tip, crimper for your chosen
connector, hex keys, digital calipers, a multimeter, and a bench supply with a
current limit if you have one.

**Print everything first.** `CAD_README.md` §4. The `lid_frame` is a ~9 hour
print — start it, then build the electronics while it runs.

**Install the heat-set inserts** into every printed part before assembly.
Iron at 220 °C, insert square, press until flush, let it cool before loading
it. Doing this after the part is mounted is miserable.

---

## 3. Electronics bring-up (bench)

### 3.1 Power first, and prove it

Wire the PSU → master switch → fuse → distribution bar → servo rail, with the
1000 µF bulk capacitor fitted. **Before connecting anything else:**

- [ ] Multimeter: no continuity 5 V ↔ GND
- [ ] Power on. Measure 5.0 V ±0.25 V at the servo rail
- [ ] Master switch off. Rail drops to 0 V
- [ ] GPIO38 driver: with the ESP32 unpowered, the servo rail is **off**

That last check is the important one. The safe state must be the default
state.

### 3.2 Then the logic

Power the ESP32-S3 from USB while you work — it isolates board faults from
rail faults. Only tie the two together once both are proven.

**Star ground.** Every ground returns to one bolt. Not daisy-chained, not
through the ESP32's ground pins. See `WIRING.md` §1, rule 2.

### 3.3 I²C

Bring the bus up with **one device at a time** and confirm each address:

```
0x3C  SSD1306
0x30  VL53L0X throat      (after XSHUT re-addressing)
0x31  VL53L0X approach
```

If the second ToF never appears, XSHUT is floating — that is the whole reason
GPIO47/48 exist. See `TROUBLESHOOTING.md` §3.

---

## 4. Lid assembly

1. Fit `hinge_body` ×2 to the collar; `hinge_lid` ×2 to the lid pads.
2. Slide the 4 mm pin through. **The lid must fall freely under its own
   weight** through the whole arc. If it binds anywhere, fix that now — a
   stiff hinge eats your entire torque margin and no amount of firmware will
   save it.
3. Mount `servo_mount` to the inside of the collar, screws finger-tight in
   the slots.
4. Fit the servo. **Do not fit the horn yet.**
5. Power up and let the firmware drive the servo to `LID_ANGLE_CLOSED` (12°).
6. *Now* fit the horn, at the angle that puts the lid on its closed stop.
7. Fit `linkage` between the horn and the lid anchor with M3 shoulder screws.
8. Fit `lid_stop` ×2 with their TPU pads at both ends of travel.

Step 5–6 ordering matters: fitting the horn while the servo is at an unknown
angle is how you end up with only 40° of usable travel.

### 4.1 Limit switches

Mount both microswitches so they are made **just before** the mechanical stop,
not at the same instant. The firmware wants the switch to confirm arrival
while the servo still has a degree or two in hand.

Wire **COM → GND, NC → GPIO**, so a severed wire reads as "not closed" and
faults safe.

---

## 5. Finger cartridge

Assemble and test this **on the bench, out of the bin**. It is much easier to
adjust in your hand.

1. Fit both micro servos to `servo_plate`.
2. Drive them to `DOOR_ANGLE_SHUT` (8°) and `FINGER_ANGLE_HOME` (18°), then
   fit the horns.
3. Fit `finger` to the extend servo; push the TPU `finger_tip` into its socket.
4. Fit `door` on its 2 mm pin, and link it to the door servo horn.
5. Run a full cycle. Watch for the finger fouling the hatch on the way out.

### 5.1 The reach check — do not skip this

Hold `button_plate` where it will be mounted. Run the cycle. **The finger tip
must land inside the printed witness ring**, and must overshoot the switch
face by roughly 6 mm so the switch is fully thrown.

- Tip lands short → move the button plate closer, or increase
  `FINGER_ANGLE_PRESS`.
- Tip lands long, servo strains → decrease `FINGER_ANGLE_PRESS`.
- Tip misses sideways → the cartridge is not square. Fix the mount, not the
  firmware.

Sand off the witness ring once you are happy.

---

## 6. Final assembly

Bottom-up, per the exploded diagram:

1. **Base** — TPU feet, PSU, master switch, fuse holder, IEC/barrel inlet.
2. **Body** — waste liner, `tray_rails`, then slide the tray in.
3. **Tray** — ESP32-S3, distribution perfboard, buck (if used), amp. All on
   screws. Nothing glued.
4. **Finger cartridge + button plate** — four screws, one connector.
5. **Face panel** — `oled_bezel`, eye assembly, both `tof_bracket`s, speaker
   grille.
6. **Collar** — hinge mounts, `lid_stop`s, LED strip in `led_diffuser`.
7. **Lid** — drop on, insert the hinge pin.
8. **Service panel** — last, so you can still get at everything.

Leave a **service loop** in the lid servo loom. The lid moves; the loom must
not be in tension at either end of travel.

---

## 7. Calibration

### 7.1 Lid endpoints — do this first

With the linkage fitted, in `settings.h`:

1. Set `LID_ANGLE_CLOSED` so the lid rests on its stop with the servo
   **not straining**. Listen: a servo holding against a hard stop hums. If it
   hums, back the angle off by 2° and reflash.
2. Set `LID_ANGLE_OPEN` so the lid is fully back but again not straining.
3. If the lid moves the wrong way, set `LID_INVERT = true`. Do not try to fix
   it by swapping the angles.
4. Confirm both limit switches assert at their endpoints. If
   `[lid] endpoint N not confirmed` appears, adjust the switch position, not
   the timeout.

Reference build: `LID_ANGLE_CLOSED 12`, `LID_ANGLE_OPEN 96`.

### 7.2 ToF thresholds

Watch the heartbeat and note the numbers for your geometry:

| Symbol | Set it to | Reference |
|---|---|---|
| `TOF_THROAT_OBJECT_MM` | comfortably above your empty-throat reading | 200 mm |
| `TOF_THROAT_CLEAR_MM` | 50–60 mm above `OBJECT_MM` (this gap is the hysteresis) | 260 mm |
| `SAFETY_HAND_MM` | far enough out that a hand is caught **before** the lid reaches it | 130 mm |
| `TOF_APPROACH_NEAR_MM` | where you want it to notice people | 900 mm |
| `TOF_APPROACH_FAR_MM` | 400–500 mm beyond NEAR | 1400 mm |

Test `SAFETY_HAND_MM` deliberately and repeatedly: put your hand in the
opening while the lid is closing. It must stop and reverse **every single
time**. See `TEST_PLAN.md` §2.

### 7.3 Eye endpoints

Drive the pan servo to its limits by hand-editing `EYE_PAN_MIN` / `MAX` until
the eye reaches the edges of its aperture without the yoke binding. Same for
tilt. Reference: pan 35–145, tilt 62–118.

### 7.4 Finger angles

Covered in §5.1. Reference: `DOOR_ANGLE_SHUT 8`, `DOOR_ANGLE_OPEN 92`,
`FINGER_ANGLE_HOME 18`, `FINGER_ANGLE_PRESS 112`.

### 7.5 Remote ladder

Set `CALIBRATE_LADDER 1` in the remote's `pins.h`, flash, open the serial
monitor, press each aux button, and paste the readings into `LADDER_CENTERS`.
Set it back to 0. Details in `PINOUT.md` §2.3.

### 7.6 Timing and feel

Once everything works mechanically, tune for comedy:

| Symbol | Default | Effect |
|---|---:|---|
| `LID_MS_CLOSE` | 900 | Lower = snappier, higher = more deliberate. Never below ~500. |
| `MISS_SILENCE_MS` | 2000 | The judgemental pause. **Leave it at 2000.** |
| `FINGER_PAUSE_MS` | 900 | The beat between the hatch opening and the finger appearing. This is the single most important number for the punchline. |
| `NORMAL_MODE_GRACE_MS` | 4500 | How long the bin behaves. Long enough to be convincing, short enough that the audience does not lose interest. |
| `THROW_WINDOW_MS` | 2600 | How long it waits before declaring a miss. |

---

## 8. First full power-on

- [ ] Bin on a stable surface, lid clear, hands clear
- [ ] Bench supply current-limited to 3 A if you have one
- [ ] Power on. Self-test runs: EYE, LEDS, AUDIO, LID, FINGER, SENSORS, REMOTE
- [ ] Any `FAIL` line — stop, fix, repeat. Do not carry on with a known fault
- [ ] `USELESSNESS 100%` appears
- [ ] Idle: eye drifts and blinks, LEDs breathe, lid still, servos silent
- [ ] Heartbeat every 5 s on serial, values sensible
- [ ] **Obstruction test** before letting anyone near it (`TEST_PLAN.md` §2)

Silence at idle is a real check, not a nicety — if you hear servo hunting, the
detach logic is not running, and you are wasting a few hundred mA and
shortening the servos' life.

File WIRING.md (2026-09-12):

# WIRING

Power architecture

Complete connection table, power budget and the three wiring rules that
account for most of the failures people hit on this kind of build.

---

## 1. The three rules

**1. Servos never draw current through the ESP32.**
The dev board's 5 V pin is fed through a diode and a narrow trace. An MG996R
stalls at 2.5 A. Give the servos their own rail straight from the PSU.

**2. One star ground.**
Servo return current is spiky and large. If it shares a wire with the ToF
sensors' ground, the resulting few hundred millivolts of ground bounce shows
up as phantom range readings. All grounds meet at one bolt/bar, and only there.

**3. The master switch cuts actuator power, not logic.**
When something jams you want the motors dead and the display still telling you
why. The master switch and the GPIO38 soft-cutoff both act on the servo rail.

---

## 2. Power budget

Measured/datasheet worst case, main controller:

| Load | Qty | Idle | Moving | Stall / peak |
|---|---:|---:|---:|---:|
| MG996R — lid | 1 | 10 mA (detached) | 500–900 mA | 2500 mA |
| MG90S — eye pan | 1 | 5 mA | 150 mA | 700 mA |
| MG90S — eye tilt | 1 | 5 mA | 150 mA | 700 mA |
| SG90 — finger | 1 | 5 mA | 130 mA | 650 mA |
| SG90 — hatch | 1 | 5 mA | 130 mA | 650 mA |
| WS2812B ×12 | 12 | — | 220 mA @ brightness 90 | 720 mA all-white |
| MAX98357A + 4 Ω | 1 | 3 mA | 300 mA | 900 mA transient |
| ESP32-S3 + sensors + OLED | — | 90 mA | 240 mA (Wi-Fi TX) | 500 mA |

**Realistic simultaneous worst case** — lid moving, eye tracking, LEDs on,
audio playing: roughly **2.4 A**.
**Absolute worst case** with every servo stalled: about **6.5 A**, which the
firmware never commands and the mechanical stops prevent.

Specify a **5 V 5 A (25 W)** supply. That gives 2× headroom on the realistic
case and rides out the stall transients on the bulk capacitance.

> The firmware detaches idle servos (`LID_IDLE_DETACH_MS`, `EYE_IDLE_DETACH_MS`),
> so between interactions the whole machine sits at roughly 350 mA. This is
> also why the bin is silent when idle — a parked-but-attached analogue servo
> hunts and buzzes.

---

## 3. Power distribution

```
      ┌──────────────┐
      │  5 V / 5 A   │
      │   PSU        │
      └──────┬───────┘
             │  2.5 mm² / 14 AWG
      ┌──────┴───────┐
      │ MASTER SWITCH│   (DPST, 10 A — breaks 5 V to actuators)
      └──────┬───────┘
             │
      ┌──────┴───────┐
      │  FUSE 5 A    │   blade fuse in a panel holder
      └──────┬───────┘
             │
      ╞══════╪══════════════════════════════╡  5 V distribution bar
             │
   ┌─────────┼──────────┬─────────────┬──────────────┐
   │         │          │             │              │
   ▼         ▼          ▼             ▼              ▼
SERVO      LED        AUDIO        LOGIC          spare
RAIL       RAIL       RAIL         RAIL
(via       470 µF     220 µF       ESP32 5V pin
 P-FET)    + 330R                  or buck to 3V3
1000 µF    on data
```

### Decoupling — do not skip this

| Where | Part | Why |
|---|---|---|
| Servo rail, at the distribution point | 1000 µF, 10 V electrolytic, low-ESR | Absorbs servo inrush. Without it the ESP32 browns out the first time the lid moves. |
| Servo rail, at each servo connector | 100 nF ceramic | Local HF decoupling. |
| LED rail, at the first pixel | 470 µF, 10 V | WS2812 strips draw in sharp steps. |
| LED data line | 330 Ω series | Damps reflections, protects the first pixel's input. |
| Audio rail | 220 µF + 100 nF | MAX98357A pulls hard on bass transients. |
| ESP32 3V3, near the module | 10 µF + 100 nF | |

---

## 4. Connection table — main controller

### 4.1 Servos (5 pin-headers, JST-style or 0.1" 3-pin)

| Servo | Signal → GPIO | + | − |
|---|---|---|---|
| Lid (MG996R) | 4 | Servo rail 5 V | Star GND |
| Eye pan (MG90S) | 5 | Servo rail 5 V | Star GND |
| Eye tilt (MG90S) | 6 | Servo rail 5 V | Star GND |
| Finger (SG90) | 7 | Servo rail 5 V | Star GND |
| Hatch (SG90) | 15 | Servo rail 5 V | Star GND |

Signal wires carry only a few mA — 26 AWG is fine. Power wires to the lid
servo should be 20 AWG or heavier.

### 4.2 Servo rail cutoff (GPIO38)

A high-side P-channel MOSFET switch, driven by a small N-FET so the logic is
the right way up:

```
                     5 V rail in
                          │
                  ┌───────┴────────┐
             ┌────┤ S   P-FET (e.g. IRF4905, AO3401 for low current)
             │    │ G           D ├────► SERVO RAIL OUT
             │    └───────┬────────┘
          10k│            │
             │            │
   GPIO38 ──[1k]──┤ G  N-FET (2N7002 / 2N7000)
                  │ S ── GND
```

- GPIO38 **HIGH** → N-FET on → P-FET gate pulled low → servo rail **on**.
- GPIO38 **LOW / floating / ESP32 unpowered** → servo rail **off**.

That last line is the point: the safe state is the default state.

For currents above ~3 A, use a proper high-side load switch or an automotive
relay instead of a small SOT-23 P-FET.

### 4.3 I²C bus

| Device | SDA | SCL | VIN | GND | Addr |
|---|---|---|---|---|---|
| VL53L0X — throat | 8 | 9 | 3V3 | Star GND | 0x30 |
| VL53L0X — approach | 8 | 9 | 3V3 | Star GND | 0x31 |
| SSD1306 OLED | 8 | 9 | 3V3 | Star GND | 0x3C |

Plus `XSHUT`: throat → GPIO47, approach → GPIO48.

One pair of 4.7 kΩ pull-ups to **3V3** total for the whole bus. Adafruit
VL53L0X breakouts include 10 kΩ pull-ups; three modules in parallel gives
~3.3 kΩ, which is still fine at 400 kHz over short wires. Keep the I²C run
under 300 mm, and route it away from the servo power wires — twisting SDA/SCL
with a ground wire helps if you must run them alongside.

### 4.4 Switches and buttons

All are wired **switch → GPIO, other side → GND**, with the internal pull-up
enabled in firmware. No external resistors needed.

| Signal | GPIO | Type | Wiring note |
|---|---|---|---|
| Lid closed limit | 10 | SPDT microswitch | Use **COM → GND, NC → GPIO** so a severed wire reads "not closed". |
| Lid open limit | 11 | SPDT microswitch | Same convention. |
| NORMAL MODE | 12 | 19 mm latching pushbutton | Switch contact only; the lamp is a separate pair. |
| NORMAL MODE lamp | 2 | LED in the switch body | Through an N-FET, 5 V, with the switch's own series resistor (check your part — many 19 mm switches want 12 V; use a resistor or a 12 V feed for those). |
| Hidden trigger | 13 | Micro tactile switch | Mounted where the operator's hand rests. See the demo guide. |
| IR break-beam | 14 | 3-pin IR module OUT | Powered from 3V3. If your module is 5 V-only, level-shift the output. |

### 4.5 Audio — MAX98357A

| MAX98357A | ESP32-S3 |
|---|---|
| VIN | 5 V (audio rail) |
| GND | Star GND |
| DIN | GPIO21 |
| BCLK | GPIO17 |
| LRC | GPIO18 |
| GAIN | Leave floating for 9 dB, or tie to GND for 12 dB |
| SD | Leave floating (enabled, mono L+R) |

Speaker: 4 Ω 3 W, on the `+` / `−` screw terminals. Never ground either
speaker terminal — the output is a bridge-tied load.

### 4.6 LEDs

| WS2812B strip | To |
|---|---|
| 5 V | LED rail |
| GND | Star GND |
| DIN | GPIO16 through 330 Ω |

The ESP32-S3 outputs 3.3 V logic and WS2812B nominally wants 0.7 × VDD = 3.5 V.
It usually works. If the first pixel flickers or shows the wrong colour, add a
74AHCT125 level shifter, or power the strip from 4.5 V instead of 5 V.

---

## 5. Connection table — remote

| Signal | GPIO | Wiring |
|---|---|---|
| UP / DOWN / LEFT / RIGHT / OK / OPEN / CLOSE | 0, 1, 3, 7, 10, 20, 21 | 16 mm buttons, one side to GPIO, other to GND |
| Aux ladder | 4 | See `PINOUT.md` §2.3 |
| OLED SDA / SCL | 5 / 6 | 3V3 + GND from the board |
| Status LED | 8 | Onboard, no wiring |
| SECRET | 9 | Onboard BOOT button |

Power: a 2000 mAh Li-ion cell into the board's battery input, or simply a USB
power bank in the battery compartment. The remote draws ~45 mA average, so
either lasts a full event. There is no charging circuit in this design — if
you add a TP4056, keep it away from the antenna, which is decorative and
therefore attracts curiosity.

---

## 6. Loom and strain relief

- Use JST-XH or Dupont **with locking shells** for anything that crosses a
  module boundary. A vibrating servo will walk a bare Dupont pin off its
  header in about forty lid cycles.
- Label both ends of every harness. The tray slides out with the loom
  attached; you will still need to unplug it eventually.
- Route servo power and I²C on opposite sides of the tray.
- Cable-tie the lid servo's loom to the body **with a service loop** — the
  lid moves, the loom must not be in tension at either end of travel.
- Heat-shrink every solder joint. Splices inside a machine that shakes itself
  are a failure looking for an audience.

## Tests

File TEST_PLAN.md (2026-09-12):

# TEST PLAN

Run §2 before anyone who is not you touches this machine. Run it again after
any change to the lid, the sensors, or `settings.h`.

Record results in the tables. A test you did not write down is a test you did
not run.

---

## 1. Bring-up smoke test

| # | Test | Pass criteria | ✓ |
|---:|---|---|---|
| 1.1 | Power on | Self-test completes, no `FAIL` lines | ☐ |
| 1.2 | Serial heartbeat | Ticks every 5 s, values sensible | ☐ |
| 1.3 | Idle silence | No servo hunting or buzzing after 2 s idle | ☐ |
| 1.4 | Idle current | ≤ 400 mA at the PSU | ☐ |
| 1.5 | I²C scan | 0x3C, 0x30, 0x31 all present | ☐ |
| 1.6 | Display | Eye animates and blinks | ☐ |
| 1.7 | LEDs | Idle breathe, no flicker on pixel 1 | ☐ |
| 1.8 | Audio | `boot.wav` audible, no hiss between clips | ☐ |

---

## 2. SAFETY — mandatory, non-negotiable

**This section gates everything else.** If any test here fails, the machine
does not get demonstrated until it is fixed.

| # | Test | Method | Pass criteria | ✓ |
|---:|---|---|---|---|
| 2.1 | Hand in the closing zone | Trigger a close, put a hand in the opening | Lid stops and reverses **within 100 ms**. Display: `OH. SORRY.` | ☐ |
| 2.2 | Repeat 2.1 × 20 | Twenty consecutive trials | **20/20.** Not 19. | ☐ |
| 2.3 | Obstruction at each point in travel | Intervene early, mid, and late in the close | Stops and reverses at every point | ☐ |
| 2.4 | Soft object | A rolled sock, not a hand | Detected and reversed | ☐ |
| 2.5 | Persistent obstruction | Leave the hand in place | Retries `LID_MAX_RETRIES`, then **stays open** and stops trying | ☐ |
| 2.6 | IR channel alone | Unplug the throat ToF, repeat 2.1 | Still stops (the safety input is OR-ed) | ☐ |
| 2.7 | ToF channel alone | Reconnect ToF, unplug IR, repeat 2.1 | Still stops | ☐ |
| 2.8 | Master switch under load | Hit it mid-travel | All actuator power dies immediately; display stays alive | ☐ |
| 2.9 | Soft E-stop | Trigger `emergencyStop()` | Servo rail drops, lid holds position | ☐ |
| 2.10 | Cold-start safe state | ESP32 unpowered, PSU on | Servo rail is **off**; nothing twitches | ☐ |
| 2.11 | Pinch force | Close the lid onto a kitchen scale | Peak force is low enough to be harmless, and it reverses off the scale | ☐ |
| 2.12 | Sharp edges | Run a hand over every user-reachable surface | Nothing sharp. Finger tip is soft TPU | ☐ |
| 2.13 | Angry mode is still safe | Force `P_ANGRY`, repeat 2.1 | Obstruction detection **unchanged**. Comedy does not override safety | ☐ |

Test 2.13 exists because it is the exact thing a rushed developer breaks.

---

## 3. Lid endurance

| # | Test | Pass criteria | ✓ |
|---:|---|---|---|
| 3.1 | 100 open/close cycles | All complete. `cyc=100` in the heartbeat | ☐ |
| 3.2 | Endpoint confirmation | Zero `endpoint not confirmed` messages in 100 cycles | ☐ |
| 3.3 | Servo temperature after 100 | Warm, not hot to hold | ☐ |
| 3.4 | Hinge check after 100 | No visible wear or slop at the pin | ☐ |
| 3.5 | Linkage check after 100 | No elongation of the screw holes | ☐ |
| 3.6 | Rail voltage during travel | Never below 4.6 V | ☐ |
| 3.7 | 500 cycles (optional soak) | Same as 3.1–3.5 | ☐ |

Cycle it with the remote's OPEN button held, or add a temporary loop to
`ST_IDLE`. Watch the first ten, then leave it.

---

## 4. Finger mechanism

| # | Test | Pass criteria | ✓ |
|---:|---|---|---|
| 4.1 | 100 activation cycles | All complete, hatch closes fully each time | ☐ |
| 4.2 | Switch actuation reliability | Switch reads OFF after each cycle. **100/100** | ☐ |
| 4.3 | User holds the switch down | Retries once, then `FINGER JAMMED BY USER`. No stall damage | ☐ |
| 4.4 | Hatch clearance | Finger never fouls the hatch edge | ☐ |
| 4.5 | Tip wear after 100 | TPU tip intact and still seated | ☐ |
| 4.6 | Timing | Full sequence completes in < 2 s (`FINGER_*` sum) | ☐ |
| 4.7 | Interrupted cycle | Cut and restore power mid-extend | Recovers to home on next boot; nothing jams | ☐ |

---

## 5. Sensors

| # | Test | Method | Pass criteria | ✓ |
|---:|---|---|---|---|
| 5.1 | Throat range | Card at 50/100/150/200/250 mm | Readings within ±10 mm | ☐ |
| 5.2 | Approach range | Person at 0.5/1.0/1.5/2.0 m | `personNear` asserts inside 900 mm, clears past 1400 mm | ☐ |
| 5.3 | Bright ambient | Direct sunlight / stage lights on the opening | Still detects. Note any degradation | ☐ |
| 5.4 | Dark | Lights off | Unaffected (ToF is active-illumination) | ☐ |
| 5.5 | Object variety | Paper ball, can, crisp packet, banana skin | All detected passing through | ☐ |
| 5.6 | Dark/matt object | Black foam block | Detected — this is the ToF worst case | ☐ |
| 5.7 | Shiny object | Foil ball | Detected, or falls back to the IR channel | ☐ |
| 5.8 | Sensor unplugged | Disconnect the approach ToF | `healthSummary()` = `PARTIAL`, bin keeps running | ☐ |
| 5.9 | Both ToF unplugged | Disconnect both | `BLIND`, no crash, IR still triggers the lid | ☐ |
| 5.10 | Hysteresis | Wave a hand slowly at the threshold | No rapid state chatter | ☐ |

---

## 6. Remote link

| # | Test | Pass criteria | ✓ |
|---:|---|---|---|
| 6.1 | 100 commands | ≥ 99 produce a reaction (`rx` count matches) | ☐ |
| 6.2 | Latency | Reaction visibly immediate; < 200 ms | ☐ |
| 6.3 | Range at 10 m | Still reliable | ☐ |
| 6.4 | Range at 30 m | Degraded but functional | ☐ |
| 6.5 | Remote powered off | `REMOTE LOST / Good.` after 4 s. Bin keeps working | ☐ |
| 6.6 | Remote powered back on | Reconnects automatically, `REMOTE FOUND / Unfortunately.` | ☐ |
| 6.7 | Bin rebooted with remote on | Link re-establishes without touching the remote | ☐ |
| 6.8 | De-duplication | One press = exactly one reaction, never two | ☐ |
| 6.9 | Corrupt packet | Flip a byte in a test build | Rejected; `packetsRejected()` increments | ☐ |
| 6.10 | Congested Wi-Fi | Test in a busy 2.4 GHz environment | Still works (that is why it is ESP-NOW) | ☐ |

---

## 7. Behaviour and comedy

These are subjective, but test them — a joke that does not fire is a bug.

| # | Test | Pass criteria | ✓ |
|---:|---|---|---|
| 7.1 | Approach from 2 m | Eye turns to you, `OH NO.` | ☐ |
| 7.2 | Successful throw | Green sweep + an approving line within 1 s | ☐ |
| 7.3 | Miss | **Two full seconds of silence**, eye locked on you, then the line | ☐ |
| 7.4 | Three misses | Line escalates to the annoyed table | ☐ |
| 7.5 | Ten misses | Enters `P_ANGRY`, red strobe, `ENOUGH.` | ☐ |
| 7.6 | Anger cools | Returns to IDLE after ~20 s | ☐ |
| 7.7 | OPEN on the remote | Lid **closes** (most of the time) | ☐ |
| 7.8 | Six remote presses | Compliance is now zero; it never obeys again | ☐ |
| 7.9 | STOP | Everything speeds up | ☐ |
| 7.10 | MUTE | Volume goes **up** | ☐ |
| 7.11 | AI button | Progress bar climbs, stalls at 99, delivers a verdict, does something unrelated | ☐ |
| 7.12 | NORMAL MODE | Behaves normally for ~4.5 s | ☐ |
| 7.13 | **Self-disable** | Eye looks at the button → pause → hatch → pause → finger → switch OFF → retract → `NORMAL MODE CANCELLED` | ☐ |
| 7.14 | User switches NORMAL off first | `I WAS GOING TO DO THAT.` — no pointless finger deployment | ☐ |
| 7.15 | Sleep | After 90 s idle: `Zzz...`, eye closes, LEDs dim | ☐ |
| 7.16 | Wake | Approach: eye opens slowly, `WHO DISTURBED ME?` | ☐ |
| 7.17 | Hidden trigger | Produces an indistinguishable success reaction | ☐ |
| 7.18 | Line repetition | Miss ten times — never the same line twice in a row | ☐ |

---

## 8. Power

| # | Test | Pass criteria | ✓ |
|---:|---|---|---|
| 8.1 | Lid alone | No brownout, rail ≥ 4.6 V | ☐ |
| 8.2 | All five servos at once | No reset. Force it via self-test | ☐ |
| 8.3 | Servos + audio + LEDs full | No reset, no audio glitching | ☐ |
| 8.4 | Worst-case current | ≤ 3 A at the PSU | ☐ |
| 8.5 | Brownout counter | Zero `Brownout detector was triggered` in the log after a full session | ☐ |
| 8.6 | 30-minute soak | No resets, no thermal issues, PSU warm not hot | ☐ |
| 8.7 | Cold start ×10 | Boots reliably from cold every time | ☐ |

A single brownout message in 8.5 means the bulk capacitor is too small, too
far from the servos, or missing. Fix it before the demo, not after.

---

## 9. Pre-demo checklist

Run this in the 30 minutes before you present.

- [ ] §2 safety tests 2.1, 2.2, 2.8 re-run and passing
- [ ] Battery/power bank in the remote is charged
- [ ] `frustration` reset (leave the remote alone for 2 minutes, or reboot)
- [ ] Miss counter reset (reboot) so the escalation starts from the top
- [ ] Hidden trigger reachable from where you will be standing
- [ ] Throwables prepared: light, soft, and they must fit the opening
- [ ] Spare finger cartridge within reach
- [ ] Spare USB-C cable, and a laptop that can reflash
- [ ] Lid clear of obstructions; bin on a stable surface
- [ ] Volume set for the room
- [ ] Full run-through completed end to end at least once

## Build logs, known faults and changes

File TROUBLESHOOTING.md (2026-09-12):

# TROUBLESHOOTING

The failures you are actually going to hit, roughly in the order you will hit
them.

**First, always:** open the serial monitor at 115200 and read the heartbeat.

```
[hb] IDLE/IDLE lid=0 ang=0 frus=0 thr=8190mm app=1240mm cyc=37 rx=412
```

A **frozen** heartbeat means a hung `loop()` — a software problem. A heartbeat
that keeps ticking while nothing moves means a hung mechanism — a hardware
problem. Knowing which one you have saves you an hour.

---

## 1. ESP32 resets, or `Brownout detector was triggered`

**By far the most common failure on this build.** It appears the moment the
lid first moves.

| Cause | Fix |
|---|---|
| Servos powered from the ESP32's 5 V pin | Give them their own rail from the PSU. `WIRING.md` §1, rule 1. This is almost always the answer. |
| No bulk capacitance | Fit the 1000 µF **at the servo distribution point**, not next to the PSU. |
| Bulk cap too far from the servos | Move it. Wire inductance defeats a distant capacitor. |
| Undersized supply | 5 V 5 A. A 2 A phone charger will not do this. |
| Thin power wiring | 18–20 AWG on the servo rail. Voltage drop under a 2.5 A stall is real. |
| Daisy-chained grounds | Star ground. `WIRING.md` §1, rule 2. |

Confirm with a multimeter on the servo rail while the lid moves. Below 4.6 V
is your problem.

---

## 2. Servo jitter, buzzing, or hunting

| Symptom | Cause | Fix |
|---|---|---|
| Buzzes constantly while parked | Servo still attached and hunting | The firmware detaches after `LID_IDLE_DETACH_MS`. If it does not, check `lid.update()` is being called every loop. |
| Buzzes only at an endpoint | Commanded past the mechanical stop | Back `LID_ANGLE_CLOSED`/`OPEN` off by 2–3°. **Do not leave it straining** — it will cook the servo. |
| Random twitching | Noise on the signal line | Route the signal away from servo power. Keep it short. Add 100 nF at the servo. |
| Twitches at boot | Normal — servos snap to position on attach | Cosmetic. Reduce by keeping the boot angles close to the rest positions. |
| Slow or weak | Rail sagging | See §1. |

---

## 3. A VL53L0X does not appear on the bus

| Cause | Fix |
|---|---|
| **XSHUT floating** | The usual answer. Both sensors boot at 0x29; they must be held in reset and brought up one at a time. Confirm GPIO47/48 actually reach the breakouts. |
| Wrong wiring on VIN | Adafruit breakouts take 3–5 V, some clones are 3V3-only. Check yours. |
| No pull-ups | 4.7 kΩ on SDA and SCL to 3V3. |
| Too many pull-ups | Three breakouts each with 10 kΩ gives ~3.3 kΩ, which is fine. Six is not. Cut the jumpers on the extras if the bus looks sluggish. |
| I²C run too long | Keep it under 300 mm. Twist SDA/SCL with a ground wire. |
| Address collision | The OLED is 0x3C; some are 0x3D. Change `OLED_ADDR` in `display.cpp`. |

Serial says `[sensors] THROAT ToF did not answer` — that message means
`begin()` failed, so it is a bus or XSHUT problem, not a threshold problem.

---

## 4. The sensor reads 8190 forever

8190 is the driver's out-of-range marker.

| Cause | Fix |
|---|---|
| **The bracket is shadowing the emitter** | The most common mechanical cause. `tof_bracket` holds the sensor 4 mm proud with a window wider than the PCB — do not close that window up to look neater. |
| Nothing actually in range | Expected. An empty throat genuinely reads out-of-range. |
| Target too dark or too shiny | Black matt foam and mirror-finish foil are the ToF worst cases. This is why the IR channel exists. |
| Sensor pointing into open space | The approach sensor should see a wall/floor at a known distance, not infinity. |
| Cover glass fingerprinted | Clean it. |

---

## 5. False detections / the lid opens at nothing

| Cause | Fix |
|---|---|
| Threshold too close to the resting reading | Widen the gap between `TOF_THROAT_OBJECT_MM` and the empty-throat value. |
| Not enough hysteresis | Raise `TOF_CONFIRM_SAMPLES` to 3. Keep `TOF_THROAT_CLEAR_MM` at least 50 mm above `OBJECT_MM`. |
| The lid itself entering the ToF cone | Geometry problem. Re-aim the throat sensor so it never sees the lid at any angle. Check at every point in travel, not just closed. |
| IR module triggering on ambient IR | Shade it, or turn its trim pot down. Stage lights and sunlight both emit IR. |
| Ground bounce from servo current | Star ground. §1. |

---

## 6. The lid will not move / `LID ERROR`

Display shows `LID ERROR / Have you tried turning me off?`

| Cause | Fix |
|---|---|
| A limit switch never asserted | The firmware refuses to trust the servo angle alone. Check the switch is made **just before** the mechanical stop, and that it is wired COM→GND / NC→GPIO. |
| Switch wired NO instead of NC | It will read "always closed" or "never closed". Rewire. |
| Mechanical binding | Disconnect the linkage and move the lid by hand. It must fall freely through the whole arc. Fix binding mechanically — no firmware setting compensates for a stiff hinge. |
| Servo underpowered for the lid | Redo the torque sum. `CAD_README.md` §1. |
| Servo rail off | GPIO38 low, master switch off, or a blown fuse. |
| `LID_LIMIT_TIMEOUT_MS` too short for a slow close | Only raise this once you have confirmed the mechanism is genuinely fine. |

To clear a fault without a power cycle: press the hidden trigger. The bin runs
`clearError()`, homes slowly, and displays `PRETENDING THAT'S FIXED`.

---

## 7. The remote does nothing

| Cause | Fix |
|---|---|
| **Different channels** | Both ends must call `esp_wifi_set_channel()`. The single most common ESP-NOW failure — the link silently does nothing. |
| **`protocol.h` copies have diverged** | They must be byte-identical. A mismatch fails the checksum on every packet. `diff` them. |
| USB CDC On Boot disabled on the remote | GPIO20/21 are buttons. Without USB CDC they are UART0 and the remote appears dead. |
| Different `BINCHAD_DEVICE_ID` | Both must be `0x2A`. |
| Buttons held during boot on GPIO 2/8/9 | Strapping pins. Release and reset. |
| It **is** working | Check the serial log. `[remote] asked OPEN -> doing CLOSE` means the link is perfect and the bin is simply refusing you. That is the product. |

`packetsRejected()` climbing while `packetsReceived()` stays flat means
packets are arriving and failing validation — checksum, version or device ID.

---

## 8. Audio problems

| Symptom | Cause | Fix |
|---|---|---|
| Silence | LittleFS not uploaded | Tools → ESP32 Sketch Data Upload. Serial will say `missing clip /boot.wav`. |
| Silence, and `ESP_I2S.h not found` at compile | Arduino core 2.x | Upgrade to core 3.x, or set `AUDIO_BACKEND` to `AUDIO_DFPLAYER`. |
| Silence, `I2S init failed` | Pin conflict | Check GPIO17/18/21 are not double-assigned. |
| Loud hiss between clips | Amp enabled with no data | Normal for MAX98357A. Tie SD through a resistor divider, or ignore it. |
| Distorted | Clipping | Lower `AUDIO_VOLUME_DEFAULT`, or record the source clips quieter. |
| Crackling during servo movement | Shared power rail | Separate the audio rail, add the 220 µF. |
| Plays too fast/slow | Sample rate mismatch | The parser reads the rate from the file, but only 16-bit PCM is supported. Re-export as 16-bit mono. |
| Choppy | Loop starved | Something is blocking. Look for a `delay()` you added. |

---

## 9. LED problems

| Symptom | Fix |
|---|---|
| First pixel wrong colour or flickering | 3.3 V data into a 5 V strip. Add a 74AHCT125, or run the strip from 4.5 V. |
| All pixels wrong colour | Wrong colour order. Change `NEO_GRB` to `NEO_RGB` in `leds.cpp`. |
| Flickering under load | Missing 470 µF at the strip, or missing 330 Ω on the data line. |
| Dim or brownouts at full white | 12 pixels at full white is ~720 mA. Lower `LED_BRIGHTNESS`. |
| Nothing at all | Data direction — WS2812 strips are directional. Follow the arrows. |

---

## 10. Mechanical binding

| Symptom | Fix |
|---|---|
| Lid stiff at one point in the arc | Hinge brackets not coaxial. Loosen, align, retighten. |
| Lid stiff throughout | Pin bore too tight. Raise `fit_loose` and reprint, or ream the bore. |
| Linkage binding at the extremes | `link_len` wrong. That is what the slotted holes in `servo_mount` are for. |
| Finger fouls the hatch | Cartridge not square, or `DOOR_ANGLE_OPEN` too small. |
| Finger misses the switch sideways | Fix the cartridge mount, not the firmware. `BUILD_GUIDE.md` §5.1. |
| Hatch does not close fully | Door servo horn fitted at the wrong angle. Re-fit at `DOOR_ANGLE_SHUT`. |
| Grinding noise | Something is being driven into a hard stop. **Power off immediately** and find it before you strip a gearbox. |

---

## 11. Nothing works and the demo is in ten minutes

In order:

1. **Power cycle.** Watch the self-test — it tells you which subsystem failed.
2. **Check the fuse.**
3. **Reseat every connector.** Vibration walks Dupont pins off headers.
4. Anything on the self-test says `FAIL`, disable it and demo without it:
   `USE_TOF_APPROACH 0`, `USE_IR_THROAT 0`, `USE_EYE_TILT 0`,
   `AUDIO_BACKEND AUDIO_NONE`. The machine is designed to degrade.
5. **Lid dead?** Demo the remote and the finger. Still funny.
6. **Finger dead?** Swap the spare cartridge — four screws and one connector.
7. **Sensors dead?** The hidden trigger fires a complete success reaction on
   demand. Nobody in the audience can tell.
8. **Remote dead?** The bin's own behaviour and the NORMAL MODE punchline
   carry the demo on their own.

The whole architecture is built so that no single failure takes the demo down.
Use that. Do not stand there trying to fix the root cause while the judges
wait — degrade, present, fix afterwards.

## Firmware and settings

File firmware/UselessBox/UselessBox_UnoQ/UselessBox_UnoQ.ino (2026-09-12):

#include <Servo.h>
#include <Wire.h>
#include <Adafruit_GFX.h>

//Board: Arduino UNO Q (arduino:zephyr:unoq)

//Connect servo signal to D11, +5V to 5V, GND to GND
//Connect the switch between D12 and GND (internal pull-up, no resistor needed)
#define SERVO_PIN 11
#define SWITCH_PIN 12

//Built-in LED, flashes when ready, on when in attitude mode
#define LED_BUILTIN_PIN LED_BUILTIN

//Defines the range of motion for the servo, starting(resting) and ending(hitting the switch)
#define POS_START 180
#define POS_END 45

//Active buzzer - just needs HIGH/LOW, it has its own oscillator
#define BUZZER_PIN 3

//Three HC-SR04 ultrasonic sensors, read round-robin (one per loop pass).
//Any of them seeing something closer than the threshold starts the spin.
#define SENSOR_COUNT 3
const int TRIG_PINS[SENSOR_COUNT] = { 2, A0, A2 };
const int ECHO_PINS[SENSOR_COUNT] = { 4, A1, A3 };
#define ECHO_TIMEOUT_US 12000UL   // ~2 m - keeps a no-echo read from stalling the loop
#define DISTANCE_THRESHOLD_CM 20
#define ROTATE_DURATION_MS 10000UL

//IR obstacle sensor - HIGH = no object detected ("open"), LOW = object detected.
//Flip this if your module's output logic is the opposite.
#define IR_PIN 13
#define IR_NO_OBJECT HIGH
#define BUZZER_DURATION_MS 10000UL

//L298N-style motor driver
#define ENA 5
#define ENB 6
#define IN1 7
#define IN2 8
#define IN3 9
#define IN4 10
#define MOTOR_SPEED 200   // 0-255

//0.96" 4-pin SSD1306 OLED on the SDA/SCL header pins (= A4/A5 on this board)
#define FRAME_MS 50

//Face geometry
#define EYE_L_X 40
#define EYE_R_X 88
#define EYE_CY 26
#define EYE_W 32
#define EYE_H 32

enum Mood { MOOD_RELAX, MOOD_DIZZY, MOOD_ANGRY };

#define OLED_BLACK 0
#define OLED_WHITE 1

// Minimal SSD1306 driver. Adafruit_SSD1306 doesn't compile against the Zephyr
// core, and U8g2's hardware-I2C path is hard-wired to Wire - but on the UNO Q
// the SDA/SCL header pins are i2c3, which the core exposes as Wire2, so neither
// library can actually reach the panel. Adafruit_GFX only needs drawPixel, so
// subclass it and drive the bus here.
class OledFace : public Adafruit_GFX {
public:
  OledFace() : Adafruit_GFX(128, 64) {}

  // Wire2 is the SDA/SCL header; the other buses are tried only as a fallback.
  bool begin() {
    TwoWire *buses[] = { &Wire2, &Wire1, &Wire };
    const uint8_t addrs[] = { 0x3C, 0x3D };
    for (uint8_t b = 0; b < 3; b++) {
      buses[b]->begin();
      for (uint8_t a = 0; a < 2; a++) {
        buses[b]->beginTransmission(addrs[a]);
        if (buses[b]->endTransmission() == 0) {
          wire = buses[b];
          addr = addrs[a];
          initPanel();
          return true;
        }
      }
    }
    return false;
  }

  void drawPixel(int16_t x, int16_t y, uint16_t color) override {
    if (x < 0 || x >= 128 || y < 0 || y >= 64) return;
    uint16_t i = x + (y / 8) * 128;
    uint8_t bit = 1 << (y & 7);
    if (color) buf[i] |= bit;
    else buf[i] &= ~bit;
  }

  void clear() { memset(buf, 0, sizeof(buf)); }

  void flush() {
    cmd(0x21); cmd(0); cmd(127);   // column range
    cmd(0x22); cmd(0); cmd(7);     // page range
    for (uint16_t i = 0; i < sizeof(buf); i += 128) {
      wire->beginTransmission(addr);
      wire->write((uint8_t)0x40);  // data stream
      wire->write(buf + i, 128);
      wire->endTransmission();
    }
  }

private:
  void cmd(uint8_t c) {
    wire->beginTransmission(addr);
    wire->write((uint8_t)0x00);    // command stream
    wire->write(c);
    wire->endTransmission();
  }

  void initPanel() {
    static const uint8_t seq[] = {
      0xAE,              // display off
      0xD5, 0x80,        // clock divide
      0xA8, 0x3F,        // 64 rows
      0xD3, 0x00,        // no vertical offset
      0x40,              // start line 0
      0x8D, 0x14,        // charge pump on - without this the panel stays dark
      0x20, 0x00,        // horizontal addressing
      0xA1, 0xC8,        // flip both axes so the face isn't upside down
      0xDA, 0x12,        // alternating COM pins
      0x81, 0xCF,        // contrast
      0xD9, 0xF1,
      0xDB, 0x40,
      0xA4,              // follow RAM
      0xA6,              // non-inverted
      0x2E,              // scrolling off
      0xAF               // display on
    };
    for (uint8_t i = 0; i < sizeof(seq); i++) cmd(seq[i]);
  }

  TwoWire *wire = nullptr;
  uint8_t addr = 0x3C;
  uint8_t buf[1024];
};

OledFace face;
bool hasDisplay = false;
unsigned long nextFrame = 0;
bool blinking = false;
unsigned long blinkAt = 0;

Servo myservo;
int pos = POS_START;
int target = POS_START;
int seq = 0;
int rapidCount = -1;
long lastInput = 0;
bool goRandom;

int sensorIndex = 0;
bool rotating = false;
unsigned long rotateStopAt = 0;
bool buzzing = false;
unsigned long buzzStopAt = 0;

void setup() {
  pinMode(SWITCH_PIN, INPUT_PULLUP);
  pinMode(LED_BUILTIN_PIN, OUTPUT);

  pinMode(BUZZER_PIN, OUTPUT);
  digitalWrite(BUZZER_PIN, LOW);

  for (int i = 0; i < SENSOR_COUNT; i++) {
    pinMode(TRIG_PINS[i], OUTPUT);
    digitalWrite(TRIG_PINS[i], LOW);
    pinMode(ECHO_PINS[i], INPUT);
  }

  pinMode(IR_PIN, INPUT);

  pinMode(ENA, OUTPUT);
  pinMode(ENB, OUTPUT);
  pinMode(IN1, OUTPUT);
  pinMode(IN2, OUTPUT);
  pinMode(IN3, OUTPUT);
  pinMode(IN4, OUTPUT);
  motorsStop();

  // Finds its own bus and address; false only means nothing answered, which
  // shouldn't take the rest of the box down with it.
  hasDisplay = face.begin();
  if (hasDisplay) {
    face.clear();
    face.flush();
  }

  myservo.attach(SERVO_PIN);

  digitalWrite(LED_BUILTIN_PIN, HIGH);  // flash the led to show it's ready.
  gotoPercent(50, 1, 0);  // do a small initialization to show it's ready
  gotoPercent(0, 1, 0);
  digitalWrite(LED_BUILTIN_PIN, LOW);

  int switchState = digitalRead(SWITCH_PIN);
  if (switchState == LOW) { //Reads the switch at startup to set random
    goRandom = false;
  } else {
    goRandom = true;
  }

  randomSeed(micros()); //A0 is a TRIG pin now, so seed off the clock instead
}

void loop() {
  handleProximityRotate();
  handleIrBuzzer();
  drawFace();

  int switchState = digitalRead(SWITCH_PIN);
  if (switchState == LOW) {
    if ((millis() - lastInput) < 10000) {  // if the last switch ended less than 10 seconds ago, increase the number of rapid switches
      rapidCount++;
    } else {
      rapidCount = 0;
    }
    lastInput = millis();  // set the last switch to now
    if (rapidCount < 4) {   // if there have been fewer than 4 switches in a row with 10 seconds between them, just do the basic sequence.
      seq = 0;
    } else {
      if (goRandom == true) {
        seq = int(random(1, 10));
      } else {
        seq++;
        if (seq > 9) { seq = 1; }
      }
    }
    if (seq == 0) Seq00();
    if (seq == 1) Seq01();
    if (seq == 2) Seq02();
    if (seq == 3) Seq03();
    if (seq == 4) Seq04();
    if (seq == 5) Seq05();
    if (seq == 6) Seq06();
    if (seq == 7) Seq07();
    if (seq == 8) Seq08();
    if (seq == 9) Seq09();
    lastInput = millis();  // set the last switch to now
  } else {
    delay(50);
  }
  if (millis() - lastInput < 10000 && rapidCount >= 3) {  //illuminate the builtin LED when it's mad or about to be mad
    digitalWrite(LED_BUILTIN_PIN, HIGH);
  } else {
    digitalWrite(LED_BUILTIN_PIN, LOW);
  }
}

void Seq00() {
  gotoPercent(100, 3, 0);
  gotoPercent(0, 3, 0);
}

void Seq01() {
  gotoPercent(100, 3, 0);
  gotoPercent(0, 1, 0);
}

void Seq02() {
  gotoPercent(100, 1, 2000);
  gotoPercent(0, 7, 0);
}

void Seq03() {
  gotoPercent(100, 10, 0);
  gotoPercent(75, 1, 1000);
  gotoPercent(100, 10, 0);
  gotoPercent(75, 10, 0);
  gotoPercent(100, 10, 0);
  gotoPercent(0, 5, 0);
}

void Seq04() {
  gotoPercent(25, 1, 500);
  gotoPercent(50, 1, 500);
  gotoPercent(75, 1, 2000);
  gotoPercent(100, 10, 0);
  gotoPercent(0, 5, 0);
}

void Seq05() {
  gotoPercent(50, 5, 0);
  gotoPercent(0, 1, 300);
  gotoPercent(75, 5, 0);
  gotoPercent(0, 1, 300);
  gotoPercent(80, 5, 1000);
  gotoPercent(70, 5, 0);
  gotoPercent(100, 10, 0);
  gotoPercent(0, 3, 0);
}

void Seq06() {
  gotoPercent(100, 3, 0);
  gotoPercent(80, 1, 500);
  gotoPercent(100, 8, 500);
  gotoPercent(80, 1, 500);
  gotoPercent(100, 8, 500);
  gotoPercent(80, 1, 500);
  gotoPercent(50, 1, 500);
  gotoPercent(25, 1, 500);
  gotoPercent(0, 1, 0);
}

void Seq07() {
  gotoPercent(100, 2, 0);
  for (int i = 0; i < 10; i++) {
    gotoPercent(80, 3, 0);
    gotoPercent(100, 6, 0);
  }
  gotoPercent(100, 6, 2000);
  gotoPercent(50, 1, 500);
  gotoPercent(0, 1, 0);
}

void Seq08() {
  for (int i = 30; i <= 100; i += 10) {
    gotoPercent(i, 7, 0);
    gotoPercent(i - 30, 4, 0);
  }
  gotoPercent(0, 5, 0);
}

void Seq09() {
  for (int i = 0; i < random(10, 20); i++) {
    gotoPercent(random(0, 80), random(1, 10), random(0, 500));
  }
  gotoPercent(100, random(1, 10), random(0, 500));
  gotoPercent(0, random(1, 10), 0);
}

// Reads one HC-SR04. Returns distance in cm, or -1 if nothing echoed back (out of range).
long readDistanceCM(int trigPin, int echoPin) {
  digitalWrite(trigPin, LOW);
  delayMicroseconds(2);
  digitalWrite(trigPin, HIGH);
  delayMicroseconds(10);
  digitalWrite(trigPin, LOW);

  unsigned long duration = pulseIn(echoPin, HIGH, ECHO_TIMEOUT_US);
  if (duration == 0) return -1;
  return duration * 0.0343 / 2;
}

// Any sensor seeing something within DISTANCE_THRESHOLD_CM -> spin in place (CCW)
// for ROTATE_DURATION_MS. One sensor is read per pass so three pulseIn timeouts
// never stack up in a single loop. Doesn't retrigger while already spinning.
void handleProximityRotate() {
  if (rotating) {
    if (millis() >= rotateStopAt) {
      motorsStop();
      rotating = false;
    }
    return;
  }

  long distance = readDistanceCM(TRIG_PINS[sensorIndex], ECHO_PINS[sensorIndex]);
  sensorIndex = (sensorIndex + 1) % SENSOR_COUNT;

  if (distance > 0 && distance < DISTANCE_THRESHOLD_CM) {
    motorsRotateCCW();
    rotating = true;
    rotateStopAt = millis() + ROTATE_DURATION_MS;
  }
}

// IR reports no object ("open") -> buzzer on for BUZZER_DURATION_MS.
void handleIrBuzzer() {
  if (buzzing) {
    if (millis() >= buzzStopAt) {
      digitalWrite(BUZZER_PIN, LOW);
      buzzing = false;
    }
    return;
  }

  if (digitalRead(IR_PIN) == IR_NO_OBJECT) {
    digitalWrite(BUZZER_PIN, HIGH);
    buzzing = true;
    buzzStopAt = millis() + BUZZER_DURATION_MS;
  }
}

void motorsStop() {
  analogWrite(ENA, 0);
  analogWrite(ENB, 0);
  digitalWrite(IN1, LOW);
  digitalWrite(IN2, LOW);
  digitalWrite(IN3, LOW);
  digitalWrite(IN4, LOW);
}

// Motor A reverse + Motor B forward = rotate in place. If your box spins CW
// instead of CCW, swap the IN1/IN2 pair (or IN3/IN4 - whichever is wrong).
void motorsRotateCCW() {
  analogWrite(ENA, MOTOR_SPEED);
  analogWrite(ENB, MOTOR_SPEED);
  digitalWrite(IN1, LOW);
  digitalWrite(IN2, HIGH);
  digitalWrite(IN3, HIGH);
  digitalWrite(IN4, LOW);
}

// Angry beats dizzy beats relax, so the loudest thing on the box is what the face shows.
void drawFace() {
  if (!hasDisplay) return;
  if (millis() < nextFrame) return;
  nextFrame = millis() + FRAME_MS;

  Mood mood = MOOD_RELAX;
  if (buzzing) mood = MOOD_ANGRY;
  else if (rotating) mood = MOOD_DIZZY;

  face.clear();
  if (mood == MOOD_ANGRY) drawAngry();
  else if (mood == MOOD_DIZZY) drawDizzy();
  else drawRelax();
  face.flush();
}

void drawRelax() {
  unsigned long now = millis();
  if (!blinking && now >= blinkAt) {
    blinking = true;
    blinkAt = now + 120;                   // eyelid stays shut this long
  } else if (blinking && now >= blinkAt) {
    blinking = false;
    blinkAt = now + random(2000, 5000);    // then wait a while before the next one
  }

  int h = blinking ? 5 : EYE_H;
  int gaze = (int)(6 * sin(now / 900.0));  // slow idle drift, left and right

  drawEye(EYE_L_X + gaze, h);
  drawEye(EYE_R_X + gaze, h);

  // gentle smile
  face.drawLine(48, 50, 64, 56, OLED_WHITE);
  face.drawLine(64, 56, 80, 50, OLED_WHITE);
}

void drawDizzy() {
  float phase = millis() / 130.0;
  drawSpiral(EYE_L_X, EYE_CY, phase);
  drawSpiral(EYE_R_X, EYE_CY, -phase);   // counter-rotating sells the wooziness

  // woozy wavy mouth
  for (int x = 44; x <= 84; x++) {
    int y = 53 + (int)(3 * sin((x + millis() / 60.0) / 4.0));
    face.drawPixel(x, y, OLED_WHITE);
  }
}

void drawAngry() {
  int shake = (millis() / 60) % 2 ? 2 : -2;

  drawEye(EYE_L_X + shake, EYE_H);
  drawEye(EYE_R_X + shake, EYE_H);

  // Carve the brows back out in black: each wedge is flat on the outer edge and
  // dips toward the nose, which is what reads as "angry" rather than "surprised".
  int top = EYE_CY - EYE_H / 2;
  int lx = EYE_L_X + shake - EYE_W / 2;
  int rx = EYE_R_X + shake - EYE_W / 2;
  face.fillTriangle(lx, top, lx + EYE_W, top, lx + EYE_W, top + 15, OLED_BLACK);
  face.fillTriangle(rx, top, rx + EYE_W, top, rx, top + 15, OLED_BLACK);

  // frown
  face.drawLine(48, 56, 64, 50, OLED_WHITE);
  face.drawLine(64, 50, 80, 56, OLED_WHITE);
}

void drawEye(int cx, int h) {
  int r = h / 2 < 8 ? h / 2 : 8;
  face.fillRoundRect(cx - EYE_W / 2, EYE_CY - h / 2, EYE_W, h, r, OLED_WHITE);
}

void drawSpiral(int cx, int cy, float phase) {
  for (float a = 0; a < 15.7; a += 0.12) {   // 2.5 turns
    float r = a * 1.05;
    int x = cx + (int)(cos(a + phase) * r);
    int y = cy + (int)(sin(a + phase) * r);
    face.drawPixel(x, y, OLED_WHITE);
    face.drawPixel(x, y + 1, OLED_WHITE);
  }
}

// Required parameters:
//   targetPC   - Target percent (as an integer) 0-100, 0 is starting position, 100 is hitting the switch
//   steps      - Degrees per 10 ms update
//   afterDelay - Adds a delay after completing the move
void gotoPercent(int targetPC, int steps, int afterDelay) {
  target = POS_START + ((POS_END - POS_START) * targetPC * .01);
  while (pos != target) {
    if (target < pos) {
      if (pos - target < steps) {
        pos = target;
      } else {
        pos -= steps;
      }
    } else {
      if (target - pos < steps) {
        pos = target;
      } else {
        pos += steps;
      }
    }
    myservo.write(pos);
    delay(10);
  }
  if (afterDelay > 0) delay(afterDelay);
}

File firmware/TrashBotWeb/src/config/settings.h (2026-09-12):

// =============================================================================
//  settings.h - every tunable number in the TRASHBOT web remote.
//
//  Values that must survive a reflash (motor calibration, Wi-Fi credentials)
//  are defaults only - the live copy lives in NVS and is edited from the
//  SETUP tab in the browser. Everything else is compile-time.
// =============================================================================
#pragma once
#include <stdint.h>

#define TRASHBOT_VERSION "0.2.0"
#define SERIAL_BAUD      115200

// ---------------------------------------------------------------------------
// NETWORK
//
//   STA first. If there are no stored credentials, or the join fails inside
//   WIFI_CONNECT_TIMEOUT_MS, the board brings up its own AP instead so the
//   remote still works in a room with no usable Wi-Fi. Either way the UI is
//   at http://trashcan.local (mDNS) or the raw IP printed on the serial port.
// ---------------------------------------------------------------------------
// Macros rather than constants: a string constant that a translation unit
// does not happen to use is an unused-variable warning, and this header is
// included everywhere.
#define WIFI_HOSTNAME "trashcan"

static const uint32_t WIFI_CONNECT_TIMEOUT_MS = 12000;
static const uint32_t WIFI_RETRY_MS           = 20000;   // STA retry while in AP fallback

// AP fallback. The password is not protecting anything valuable, but an open
// AP would let anyone in the room drive the motors, so it is set and WPA2.
// Change it from the SETUP tab; 8 characters is the WPA2 minimum.
#define AP_SSID_DEFAULT "TRASHBOT-SETUP"
#define AP_PASS_DEFAULT "uselessbin"

static const uint16_t HTTP_PORT               = 80;
static const uint16_t WS_MAX_FRAME_BYTES      = 512;     // anything larger is refused unparsed
static const uint8_t  WS_MAX_CLIENTS          = 4;

// ---------------------------------------------------------------------------
// MOTORS / L298N
//
//   Duty is 8-bit. MIN_DUTY exists because a loaded DC motor below roughly
//   25% duty will buzz and heat instead of turning: any non-zero request is
//   lifted to MIN_DUTY so "slow" means slow, not stalled.
//
//   DECEL_MULT is the one asymmetry that matters: stopping is always allowed
//   to outrun starting. Never set it below 1.
// ---------------------------------------------------------------------------
static const uint32_t MOTOR_PWM_FREQ_HZ       = 5000;    // inaudible, well inside L298N range
static const uint8_t  MOTOR_PWM_BITS          = 8;
static const uint8_t  MOTOR_DUTY_CEILING      = 255;     // absolute hardware limit
static const uint8_t  MOTOR_DEFAULT_MAX_DUTY  = 200;     // conservative until calibrated
static const uint8_t  MOTOR_DEFAULT_MIN_DUTY  = 70;
static const uint8_t  MOTOR_DEFAULT_ACCEL     = 12;      // duty per tick: 0 -> 200 in ~330 ms
static const uint8_t  MOTOR_LAZY_ACCEL        = 2;       // LAZY drive mode
static const uint8_t  MOTOR_DECEL_MULT        = 3;
static const uint16_t MOTOR_TICK_MS           = 20;      // ramp update period
static const uint16_t MOTOR_TEST_MAX_MS       = 2000;    // calibration jog auto-expires

// ---------------------------------------------------------------------------
// SAFETY
//
//   Three independent timeouts, shortest first. None of them can be extended,
//   suppressed or delayed by the personality engine.
//
//     DRIVE_TIMEOUT  no fresh drive intent      -> ramp target to zero
//     LINK_TIMEOUT   no inbound traffic at all  -> hard stop, no ramp
//     zero clients   browser gone               -> hard stop, immediately
//
//   The browser repeats a held joystick every 100 ms and pings every 400 ms,
//   so each timeout tolerates three or four lost messages before it fires.
// ---------------------------------------------------------------------------
static const uint16_t DRIVE_TIMEOUT_MS        = 450;
static const uint16_t LINK_TIMEOUT_MS         = 1500;
static const uint16_t TELEMETRY_MS            = 100;
static const uint16_t CLIENT_PING_MS          = 400;     // documented for the browser side

// ---------------------------------------------------------------------------
// PERSONALITY
//
//   DELAY_MAX_MS is the longest the bot may sit on a command before acting.
//   It applies only to starting or changing movement - never to stopping.
// ---------------------------------------------------------------------------
static const uint16_t TRAIT_TICK_MS           = 1000;
static const uint16_t DELAY_MIN_MS            = 200;
static const uint16_t DELAY_MAX_MS            = 2500;
static const uint32_t PANIC_DURATION_MS       = 9000;
static const uint32_t IDLE_BOREDOM_MS         = 5000;    // no commands -> boredom climbs
static const uint16_t REPEAT_WINDOW_MS        = 1200;    // mashing the same key counts as nagging
static const uint16_t APOLOGY_WINDOW_MS       = 6000;    // apologies inside this get cheaper
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

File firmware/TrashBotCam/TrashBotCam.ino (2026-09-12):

// =============================================================================
//  TRASHBOT CAM
//
//  An ESP32-CAM (AI-Thinker module, OV2640) that gives the web remote a
//  camera that is not the phone's own. It runs no detector - an ESP32 cannot
//  run a useful object detector, and pretending otherwise would be the one
//  kind of lie this project does not tell. Instead it does the two things it
//  can do well:
//
//    GET /capture   one JPEG, fresh, with Access-Control-Allow-Origin: *
//    GET /stream    MJPEG, for a human to look at
//    GET /status    JSON: frame size, uptime, free heap
//
//  The phone's VISION tab points at this board, polls /capture a few times a
//  second, runs COCO-SSD in the browser, and reports the result to the bin.
//  The CORS header is what makes that possible: without it the browser may
//  display the picture but is not allowed to read its pixels.
//
//  Network: joins the bin's own access point by default (TRASHBOT-SETUP), so
//  the whole thing works in a room with no Wi-Fi. Change WIFI_SSID/PASS below
//  to put it on a house network alongside the bin instead. mDNS: trashcam.local
//
//  Wiring: nothing beyond 5 V and GND. The board's UART0 (U0T/U0R) is free
//  for programming. If you ever add an on-board detector, reportToBin() at
//  the bottom already knows how to tell the bin what it saw.
// =============================================================================
#include <WiFi.h>
#include <ESPmDNS.h>
#include <HTTPClient.h>
#include <esp_camera.h>
#include <esp_http_server.h>
#include <esp_timer.h>

// ---------------------------------------------------------------------------
// Configuration
// ---------------------------------------------------------------------------
#define WIFI_SSID      "TRASHBOT-SETUP"      // the bin's AP (see TrashBotWeb settings.h)
#define WIFI_PASS      "uselessbin"
#define HOSTNAME       "trashcam"
#define BIN_HOST       "192.168.4.1"         // where /api/vision lives, if a detector is ever added

static const framesize_t FRAME_SIZE   = FRAMESIZE_VGA;   // 640x480; the browser downscales anyway
static const int         JPEG_QUALITY = 12;              // 10..63, lower is better and bigger
static const uint32_t    WIFI_TIMEOUT_MS = 15000;

// AI-Thinker ESP32-CAM pin map. Other modules differ - check yours.
#define PWDN_GPIO_NUM     32
#define RESET_GPIO_NUM    -1
#define XCLK_GPIO_NUM      0
#define SIOD_GPIO_NUM     26
#define SIOC_GPIO_NUM     27
#define Y9_GPIO_NUM       35
#define Y8_GPIO_NUM       34
#define Y7_GPIO_NUM       39
#define Y6_GPIO_NUM       36
#define Y5_GPIO_NUM       21
#define Y4_GPIO_NUM       19
#define Y3_GPIO_NUM       18
#define Y2_GPIO_NUM        5
#define VSYNC_GPIO_NUM    25
#define HREF_GPIO_NUM     23
#define PCLK_GPIO_NUM     22
#define FLASH_LED_GPIO     4

static httpd_handle_t httpd = nullptr;
static bool cameraOk = false;

// ---------------------------------------------------------------------------
static bool startCamera() {
    camera_config_t c = {};
    c.ledc_channel = LEDC_CHANNEL_0;
    c.ledc_timer   = LEDC_TIMER_0;
    c.pin_d0 = Y2_GPIO_NUM;  c.pin_d1 = Y3_GPIO_NUM;  c.pin_d2 = Y4_GPIO_NUM;  c.pin_d3 = Y5_GPIO_NUM;
    c.pin_d4 = Y6_GPIO_NUM;  c.pin_d5 = Y7_GPIO_NUM;  c.pin_d6 = Y8_GPIO_NUM;  c.pin_d7 = Y9_GPIO_NUM;
    c.pin_xclk = XCLK_GPIO_NUM;   c.pin_pclk = PCLK_GPIO_NUM;
    c.pin_vsync = VSYNC_GPIO_NUM; c.pin_href = HREF_GPIO_NUM;
    c.pin_sccb_sda = SIOD_GPIO_NUM; c.pin_sccb_scl = SIOC_GPIO_NUM;
    c.pin_pwdn = PWDN_GPIO_NUM;   c.pin_reset = RESET_GPIO_NUM;
    c.xclk_freq_hz = 20000000;
    c.pixel_format = PIXFORMAT_JPEG;
    c.frame_size   = FRAME_SIZE;
    c.jpeg_quality = JPEG_QUALITY;
    c.fb_count     = psramFound() ? 2 : 1;
    c.fb_location  = psramFound() ? CAMERA_FB_IN_PSRAM : CAMERA_FB_IN_DRAM;
    c.grab_mode    = CAMERA_GRAB_LATEST;      // /capture must be *now*, not a stale buffer

    if (esp_camera_init(&c) != ESP_OK) return false;

    sensor_t* s = esp_camera_sensor_get();
    if (s) {
        s->set_vflip(s, 0);
        s->set_hmirror(s, 0);
    }
    return true;
}

// ---------------------------------------------------------------------------
// HTTP. esp_http_server, like the CameraWebServer example, because it copes
// with a long-lived MJPEG connection without help.
// ---------------------------------------------------------------------------
static void cors(httpd_req_t* req) {
    httpd_resp_set_hdr(req, "Access-Control-Allow-Origin", "*");
    httpd_resp_set_hdr(req, "Cache-Control", "no-store");
}

static esp_err_t captureHandler(httpd_req_t* req) {
    if (!cameraOk) {
        httpd_resp_send_err(req, HTTPD_500_INTERNAL_SERVER_ERROR, "camera not initialised");
        return ESP_FAIL;
    }
    camera_fb_t* fb = esp_camera_fb_get();
    if (!fb) {
        httpd_resp_send_err(req, HTTPD_500_INTERNAL_SERVER_ERROR, "capture failed");
        return ESP_FAIL;
    }
    cors(req);
    httpd_resp_set_type(req, "image/jpeg");
    httpd_resp_set_hdr(req, "Content-Disposition", "inline; filename=capture.jpg");
    esp_err_t r = httpd_resp_send(req, (const char*)fb->buf, fb->len);
    esp_camera_fb_return(fb);
    return r;
}

static const char* STREAM_CT   = "multipart/x-mixed-replace;boundary=frame";
static const char* STREAM_BND  = "\r\n--frame\r\n";
static const char* STREAM_PART = "Content-Type: image/jpeg\r\nContent-Length: %u\r\n\r\n";

static esp_err_t streamHandler(httpd_req_t* req) {
    if (!cameraOk) {
        httpd_resp_send_err(req, HTTPD_500_INTERNAL_SERVER_ERROR, "camera not initialised");
        return ESP_FAIL;
    }
    cors(req);
    esp_err_t r = httpd_resp_set_type(req, STREAM_CT);
    if (r != ESP_OK) return r;
    char part[64];
    while (true) {
        camera_fb_t* fb = esp_camera_fb_get();
        if (!fb) return ESP_FAIL;
        size_t n = snprintf(part, sizeof(part), STREAM_PART, (unsigned)fb->len);
        r = httpd_resp_send_chunk(req, STREAM_BND, strlen(STREAM_BND));
        if (r == ESP_OK) r = httpd_resp_send_chunk(req, part, n);
        if (r == ESP_OK) r = httpd_resp_send_chunk(req, (const char*)fb->buf, fb->len);
        esp_camera_fb_return(fb);
        if (r != ESP_OK) return r;              // the viewer went away
    }
}

static esp_err_t statusHandler(httpd_req_t* req) {
    char buf[200];
    snprintf(buf, sizeof(buf),
             "{\"camera\":%s,\"frame\":\"%s\",\"uptime\":%lu,\"heap\":%u,\"psram\":%u,\"rssi\":%d}",
             cameraOk ? "true" : "false",
             FRAME_SIZE == FRAMESIZE_VGA ? "640x480" : "other",
             (unsigned long)(esp_timer_get_time() / 1000), (unsigned)ESP.getFreeHeap(),
             (unsigned)ESP.getFreePsram(), WiFi.RSSI());
    cors(req);
    httpd_resp_set_type(req, "application/json");
    return httpd_resp_send(req, buf, strlen(buf));
}
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

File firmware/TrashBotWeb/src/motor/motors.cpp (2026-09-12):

#include "motors.h"
#include <Arduino.h>
#include <Preferences.h>
#include "../config/pins.h"
#include "../config/settings.h"
#include "../core/eventLog.h"

Motors motors;

// Arduino-ESP32 changed the LEDC API in core 3.0: channels went away and PWM
// is now bound to the pin itself. Supporting both is one #if and saves the
// single most common "it will not compile" report.
#if defined(ESP_ARDUINO_VERSION_MAJOR) && ESP_ARDUINO_VERSION_MAJOR >= 3
  #define PWM_ATTACH(pin)        ledcAttach((pin), MOTOR_PWM_FREQ_HZ, MOTOR_PWM_BITS)
  #define PWM_WRITE(pin, ch, d)  ledcWrite((pin), (d))
#else
  #define PWM_ATTACH(pin)        /* handled below with explicit channels */
  #define PWM_WRITE(pin, ch, d)  ledcWrite((ch), (d))
#endif

static const uint8_t PWM_CH_LEFT  = 0;
static const uint8_t PWM_CH_RIGHT = 1;
static const uint8_t JOG_DUTY     = 150;   // enough to turn a loaded motor, gentle enough to watch

static Preferences prefs;

static inline int16_t clampI16(int32_t v, int32_t lo, int32_t hi) {
    if (v < lo) return (int16_t)lo;
    if (v > hi) return (int16_t)hi;
    return (int16_t)v;
}

void Motors::begin() {
    pinMode(PIN_MOTOR_IN1, OUTPUT);
    pinMode(PIN_MOTOR_IN2, OUTPUT);
    pinMode(PIN_MOTOR_IN3, OUTPUT);
    pinMode(PIN_MOTOR_IN4, OUTPUT);

#if defined(ESP_ARDUINO_VERSION_MAJOR) && ESP_ARDUINO_VERSION_MAJOR >= 3
    PWM_ATTACH(PIN_MOTOR_ENA);
    PWM_ATTACH(PIN_MOTOR_ENB);
#else
    ledcSetup(PWM_CH_LEFT,  MOTOR_PWM_FREQ_HZ, MOTOR_PWM_BITS);
    ledcSetup(PWM_CH_RIGHT, MOTOR_PWM_FREQ_HZ, MOTOR_PWM_BITS);
    ledcAttachPin(PIN_MOTOR_ENA, PWM_CH_LEFT);
    ledcAttachPin(PIN_MOTOR_ENB, PWM_CH_RIGHT);
#endif

    loadCal();
    hardStop();
}

void Motors::loadCal() {
    prefs.begin("trashbot", true);
    cal_.leftInvert  = prefs.getBool("mInvL", false);
    cal_.rightInvert = prefs.getBool("mInvR", false);
    cal_.maxDuty     = prefs.getUChar("mMax", MOTOR_DEFAULT_MAX_DUTY);
    cal_.minDuty     = prefs.getUChar("mMin", MOTOR_DEFAULT_MIN_DUTY);
    cal_.accel       = prefs.getUChar("mAcc", MOTOR_DEFAULT_ACCEL);
    cal_.trim        = (int8_t)prefs.getChar("mTrim", 0);
    prefs.end();

    // A corrupt or hand-edited NVS entry must not be able to raise the
    // ceiling or stall the ramp.
    if (cal_.maxDuty == 0 || cal_.maxDuty > MOTOR_DUTY_CEILING) cal_.maxDuty = MOTOR_DEFAULT_MAX_DUTY;
    if (cal_.minDuty >= cal_.maxDuty)                           cal_.minDuty = (uint8_t)(cal_.maxDuty / 3);
    if (cal_.accel == 0)                                        cal_.accel   = MOTOR_DEFAULT_ACCEL;
    if (cal_.trim < -20) cal_.trim = -20;
    if (cal_.trim >  20) cal_.trim =  20;
}

void Motors::saveCal() {
    prefs.begin("trashbot", false);
    prefs.putBool ("mInvL", cal_.leftInvert);
    prefs.putBool ("mInvR", cal_.rightInvert);
    prefs.putUChar("mMax",  cal_.maxDuty);
    prefs.putUChar("mMin",  cal_.minDuty);
    prefs.putUChar("mAcc",  cal_.accel);
    prefs.putChar ("mTrim", cal_.trim);
    prefs.end();
    eventLog.push("CAL_SAVED", "invL=%d invR=%d max=%u min=%u accel=%u trim=%d",
                  cal_.leftInvert, cal_.rightInvert, cal_.maxDuty,
                  cal_.minDuty, cal_.accel, cal_.trim);
}

int16_t Motors::liftToMinDuty(int32_t duty) const {
    if (duty == 0) return 0;
    int32_t mag = duty < 0 ? -duty : duty;
    if (mag < cal_.minDuty) mag = cal_.minDuty;
    if (mag > cal_.maxDuty) mag = cal_.maxDuty;
    return (int16_t)(duty < 0 ? -mag : mag);
}

void Motors::setMix(int16_t leftPct, int16_t rightPct, uint8_t speedPct) {
    jogUntil_ = 0;                       // a real drive command ends a calibration jog
    if (speedPct > 100) speedPct = 100;
    leftPct  = clampI16(leftPct,  -100, 100);
    rightPct = clampI16(rightPct, -100, 100);

    int32_t scale = (int32_t)cal_.maxDuty * speedPct / 100;
    int32_t l = leftPct  * scale / 100;
    int32_t r = rightPct * scale / 100;

    // Straightness trim: only ever takes power away from the faster side, so
    // it cannot be used to exceed the ceiling.
    if (cal_.trim > 0)      l = l * (100 - cal_.trim) / 100;
    else if (cal_.trim < 0) r = r * (100 + cal_.trim) / 100;

    tgtL_ = liftToMinDuty(l);
    tgtR_ = liftToMinDuty(r);
}

void Motors::hardStop() {
    jogUntil_ = 0;
    tgtL_ = tgtR_ = 0;
    curL_ = curR_ = 0;
    writeSide(true, 0);
    writeSide(false, 0);
}

void Motors::jog(bool isLeft, int8_t dir, uint32_t now) {
    int16_t duty = (dir > 0) ? JOG_DUTY : (dir < 0 ? -JOG_DUTY : 0);
    if (isLeft) { tgtL_ = duty; tgtR_ = 0; }
    else        { tgtR_ = duty; tgtL_ = 0; }
    jogUntil_ = duty ? (now + MOTOR_TEST_MAX_MS) : 0;
}

int16_t Motors::rampAxis(int16_t cur, int16_t tgt) const {
    int16_t accel = accelOverride_ ? accelOverride_ : cal_.accel;
    if (accel < 1) accel = 1;
    int32_t decel = (int32_t)accel * MOTOR_DECEL_MULT;

    int32_t curMag = cur < 0 ? -cur : cur;
    int32_t tgtMag = tgt < 0 ? -tgt : tgt;
    // Anything that reduces the magnitude - including passing through zero on
    // a direction reversal - gets the faster of the two step sizes.
    int32_t step = (tgtMag > curMag) ? accel : decel;

    int32_t diff = (int32_t)tgt - (int32_t)cur;
    if (diff >= -step && diff <= step) return tgt;
    return (int16_t)(cur + (diff > 0 ? step : -step));
}

void Motors::tick(uint32_t now) {
    if (jogUntil_ && (int32_t)(now - jogUntil_) >= 0) {
        jogUntil_ = 0;
        tgtL_ = tgtR_ = 0;
        eventLog.push("CAL_JOG_END", "jog timed out, motor stopped");
    }

    if ((uint32_t)(now - lastTick_) < MOTOR_TICK_MS) return;
    lastTick_ = now;

    curL_ = rampAxis(curL_, tgtL_);
    curR_ = rampAxis(curR_, tgtR_);
    writeSide(true,  curL_);
    writeSide(false, curR_);
}
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

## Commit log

2026-09-12 BIN-CHAD: fill in the Useless Projects template and add the full project
    The template README is replaced with the real submission: the premise, the
    problem, the punchline sequence, complete hardware tables for all three
    machines, the ESP-NOW mistranslation table, the personality and safety
    architecture, the power budget and GPIO maps, six dashboard screenshots, the
    generated diagrams, the demo script and an honest verification status.
    Also brings in the project itself so the submission is self-contained -
    both ESP32 firmwares, the rover and its dashboard, the ESP32-CAM companion,
    the UselessBox module, 24 parametric OpenSCAD parts, the costed BOM, the
    Python tooling and the ten engineering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
    [BOM.csv, binchad_params.scad, chassis_and_tray.scad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]
2026-09-12 README: full detail on the camera, the speaker, custom voices and personality
    The audio and vision subsystems were a paragraph each. They are now four
    sections:
    - What it actually says: the thirteen-state mood machine, the anger
    accumulator and escalation ladder, and the real line tables it draws from.
    - The speaker: BIN-CHAD's MAX98357A and its thirteen replaceable WAV slots,
    the non-blocking streaming and the short-clip rule, the DFPlayer backend,
    jokeMute(); and the rover's phone-as-speaker with all 31 events, the
    clip formats and limits, the naming rules, cooldowns and the three
    simultaneous trigger links.
    - The camera: the servo-and-ToF eye that is deliberately not a camera,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
2026-09-12 README: link the Drive folder with the build photos and demo videos
    Four places: a quick-links line under the header, the Build Photos section
    (replacing the "no photographs of assembled hardware" note), the Project
    Demo video slot, and Honest status.
    Also rescopes the Honest status caveat - it now says what was not verified
    in the development environment, rather than implying the machine has never
    run, and points at the footage for what the hardware actually does.
2026-09-12 Rename the project to USELESS TRASH BIN
    Renames the display name everywhere it appears as a name: the README title
    and team name, the other documents, the source comments, the serial banner,
    and the two generated diagram titles (docs/architecture.png and
    docs/state-machine.png re-rendered).
    The OLED boot screen is now two lines. At text size 2 a glyph is 12 px wide,
    so seventeen characters would have been 204 px on a 128 px panel.
    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
2026-09-12 README: add the short Project Description above the long one
    Leads the template's Project Description section with the 4-line pitch
    (under 300 characters) suited to the Useless Projects submission form,
    keeping the detailed paragraph below it as elaboration for anyone reading
    the repo directly.
